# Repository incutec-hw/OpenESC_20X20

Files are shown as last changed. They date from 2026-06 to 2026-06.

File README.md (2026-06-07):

# OpenESC_20X20

<p>
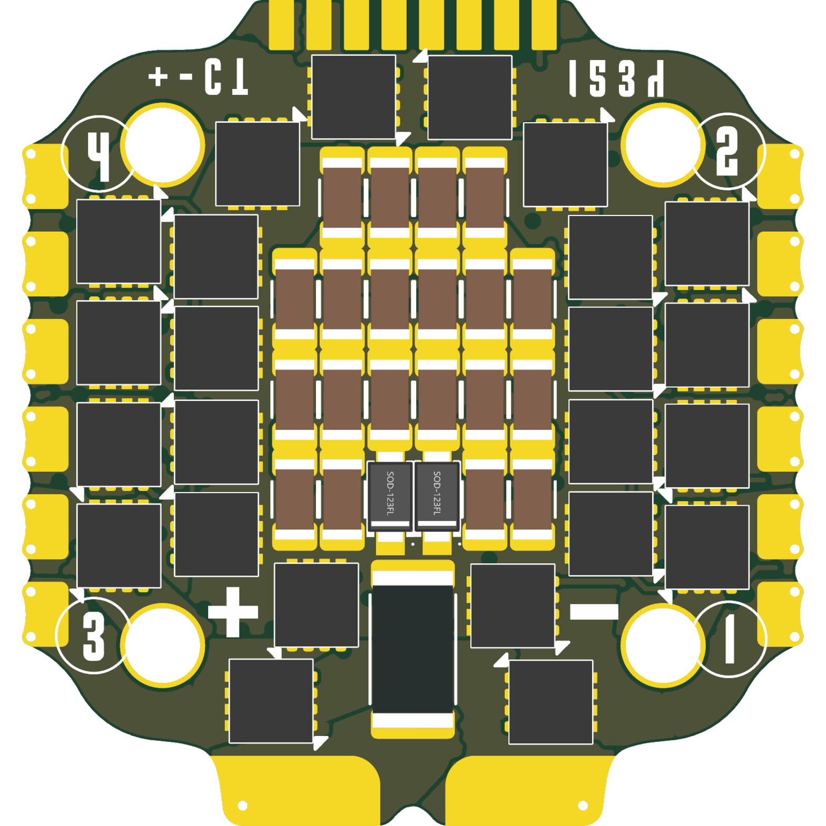
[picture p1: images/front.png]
OpenESC_20X20 top

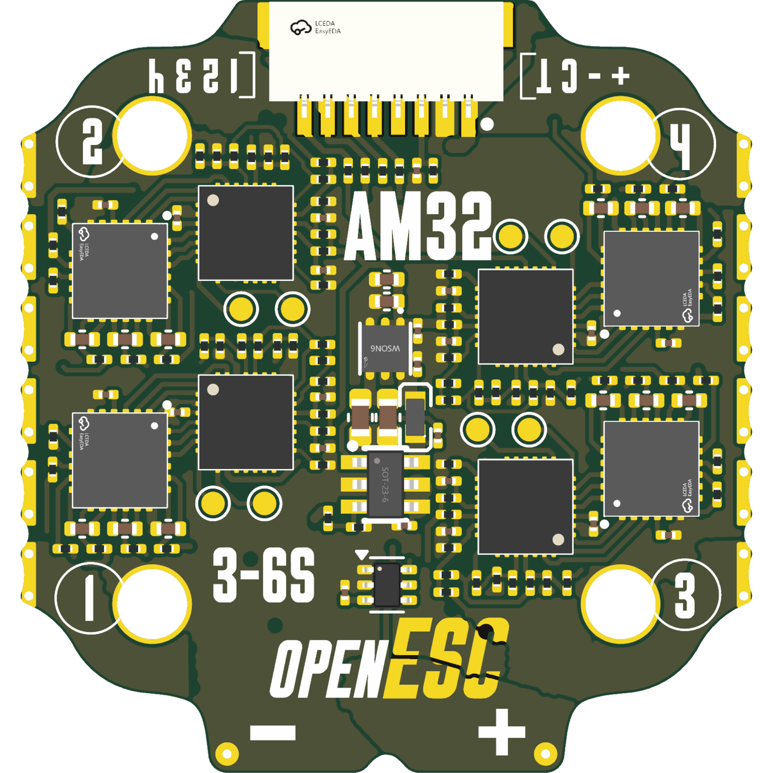
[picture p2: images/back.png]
OpenESC_20X20 bottom

</p>

Open-source 4-in-1 BLDC ESC with a 20 × 20 mm mounting pattern, built around four independent AT32F421 motor controllers running AM32. Six-layer, DShot over the standard 8-pin connector. Designed in KiCad for JLCPCB assembly.

Part of the incutec OpenDrone line (`incutec-hw/OpenESC_20X20`).

> A larger **[OpenESC-30x30](https://github.com/incutec-hw/OpenESC-30x30)** (30.5×30.5 mm) shares this design and mirrors this repo. The two differ only in board/mounting size and a few power-stage parts.

## Architecture

Four fully independent ESC channels share a common power input and telemetry connector. Each channel has its own MCU and gate driver; the high-current stage is six MOSFETs per channel (three half-bridges). This is the distributed-MCU AM32 4-in-1 topology rather than a single-MCU design. Values below are extracted from the KiCad design files (`hardware/4in1-mini.kicad_sch`, `hardware/ESC.kicad_sch`, `hardware/4in1-mini.kicad_pcb`) and the production BOM (`hardware/production/Rev2-20x20_bom.csv`).

| Block | Part | LCSC | Per board |
|---|---|---|---|
| Motor MCU | AT32F421G8U7 (QFN-28) | C2765098 | 4 |
| Gate driver | NSG2065Q (QFN-24) | C41414478 | 4 |
| Power MOSFETs | DOY180N03T PowerDI3333-8 | C49441966 | 24 (6 per channel) |

## Specifications

| Parameter | Value |
|---|---|
| Channels | 4 independent BLDC channels |
| MCU | AT32F421G8U7 (ARM Cortex-M4, QFN-28), one per channel |
| Gate driver | NSG2065Q (QFN-24, FD6288Q-compatible), one per channel |
| Power MOSFETs | DOY180N03T, 30 V, PowerDI3333-8, 24 total |
| Current sense | Board-level high-side: INA186A3IDCKR (100 V/V, SC-70-6) + 1× 0.2 mΩ 2512 shunt (Rsense1) in the +BATT feed → 20 mV/A → 165 A full-scale at 3.3 V ADC |
| Input | +BATT direct from connector/pads, 6S target |
| Input protection | 2× SMF24A-T13 TVS (24 V standoff) |
| Buck regulator | LMR54406DBVR (SOT-23-6) + FTC160808S4R7MBCA 4.7 µH inductor → +10 V gate-drive rail (FB 115k/10k, Vref 0.8 V → 10.0 V) |
| LDO | TLV76733DRVR (WSON-6) → +3V3 (MCUs, sensing), from +10 V |
| Signal protocol | DShot (4 independent signal lines, one per channel) |
| Firmware | AM32 (per-channel AT32F421 target, flashed individually) |
| PCB | 6-layer; outline ≈ 31.3 × 33.1 mm |
| Mounting pattern | 20 × 20 mm, 4× holes (M2) |

Current/voltage ratings are not printed on the design files. The input clamp is set by the SMF24A-T13 TVS (24 V standoff → 6S); the MOSFET (DOY180N03T) and current-sense full-scale (165 A) set the practical envelope. Characterize before quoting a hard rating.

## Connector

8-pin JST **SM08B-SRSS-TB** (J1). Pin-to-net mapping extracted from the schematic (net labels at the connector pins):

| Pin | Net | Function |
|---|---|---|
| 1 | +BATT | Battery positive |
| 2 | GND | Ground |
| 3 | /CURR | Current-sense telemetry (INA186 output) |
| 4 | *(unconnected)* | No dedicated telemetry pin — telemetry handled by extended DShot |
| 5 | /M1 | DShot signal, channel 1 |
| 6 | /M2 | DShot signal, channel 2 |
| 7 | /M3 | DShot signal, channel 3 |
| 8 | /M4 | DShot signal, channel 4 |

Connector ground returns on the shield/mounting pads P1/P2 (both GND). Pin 4 — the dedicated telemetry pin on the Betaflight 8-pin standard — is intentionally unconnected: ESC→FC telemetry is carried over the motor signal lines via the bidirectional **extended DShot** protocol.

## Variants and revisions

This repo is the 20×20 (mini) member of the OpenESC family; the 30×30 sibling lives in [`OpenESC-30x30`](https://github.com/incutec-hw/OpenESC-30x30). Production exports in `hardware/production/` show successive board spins; the current target is **Rev2-20x20** (`hardware/fabrication-toolkit-options.json` archive name `Rev2-20x20`). Earlier exports (`V1`, `V2`, `v0.1`–`v0.3`) are retained for history. Per the beta spec (`V_BETA_CHANGELIST.md`), this board is **6S only** (TVS-clamped); an 8S board is tracked as a separate SKU.

## Firmware

[AM32](https://github.com/AlkaMotors/AM32-MultiRotor-ESC-firmware) — incutec's default ESC firmware. Boards ship with the AM32 bootloader pre-loaded; firmware is flashed and configured in-browser at [am32.ca](https://am32.ca). Each channel's AT32F421G8U7 is an independent AM32 target. The AT32F421 + NSG2065Q per-channel topology and the DShot signal nets are the standard AM32 4-in-1 hardware target. Works with Betaflight and other DShot-capable flight controllers.

## Repository structure

```
README.md  LICENSE  CLAUDE.md            Repo root: docs + license + agent instructions
images/                                  Board render images
licensing/                               Hardware license, third-party notices, trademark policy
hardware/                                KiCad 9 project (everything to build/fab the board)
├── 4in1-mini.kicad_sch                  Top schematic (power, current sense, connector)
├── ESC.kicad_sch                        Single ESC channel sheet (instantiated 4×)
├── 4in1-mini.kicad_pcb                  Main board layout (6-layer)
├── 4in1-mini.kicad_pro                  Main project
├── components.kicad_sym                 Project-local symbol library
├── 4in1ESC.pretty/                      Project-local footprints
├── 4in1ESC.3dshapes/                   3D models (STEP)
├── fp-lib-table / sym-lib-table         Project-local library tables (${KIPRJMOD})
├── 4in1-mini.step / .glb                Exported board 3D models
├── production/                          JLCPCB fabrication exports (gerbers, BOM, CPL) per revision
├── fabrication-toolkit-options.json     KiCad Fabrication Toolkit settings
├── flash_openesc20.sh                   Production flash script (AM32 bootloader via ST-LINK)
├── datasheets/                          Component datasheets + COMPONENT_REVIEW.md
├── tools/ , scripts/                    Analysis scripts
├── V_BETA_CHANGELIST.md                 Beta spec: stackup/copper-weight, 6S-only rationale (local)
└── docs/archive/                        Design notes, alternatives, sourcing, cost analysis (local)
```

## License

Hardware: [CERN-OHL-S-2.0](https://ohwr.org/cern_ohl_s_v2.txt). See [LICENSE](LICENSE) and [licensing/](licensing/) for branding and third-party notices.

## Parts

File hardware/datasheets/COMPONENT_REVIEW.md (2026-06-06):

# Component Review — Commercial Release Audit (v0.3)

Full design review of all ICs and key components for commercial readiness.
Conducted March 2026.

---

## Critical Issues (Must Fix for v0.4)

### 1. TPS746-3.3DRV: Input Voltage Exceeds Absolute Maximum

**Severity: CRITICAL**

The TPS746-3.3DRV LDO has a maximum input voltage of 6.0V (abs max 6.5V), but the upstream LMR51420 buck converter outputs **8.04V** (set by 124kΩ/10kΩ feedback divider). This is a hard specification violation.

**Why it works in testing:** The TPS746 may survive at 8V in benign conditions, but will fail under temperature extremes, production variance, or extended operation. Not acceptable for commercial release.

**Fix:** Drop-in replacement with **TLV76733DRVR** (LCSC C2848334):
- Same WSON-6 2x2mm footprint — zero PCB changes
- Input range: 2.5V to **16V** (8V input with 2x margin)
- Output: 3.3V fixed, **1A** (upgrade from 500mA)
- Price: $0.10 (comparable to TPS746)
- Stock: 8,240 units on LCSC

**BOM change:** Replace U26 TPS746-3.3DRV (C524780) → TLV76733DRVR (C2848334)

---

### 2. INA199A1DCKR: Common-Mode Voltage Marginal for 6S

**Severity: CRITICAL**

The INA199A1 has a maximum common-mode input of **26V**. A 6S LiPo at full charge is 25.2V — only 0.8V (3%) margin. Inductive switching spikes from MOSFET commutation can easily push the battery rail to 27-28V transiently, exceeding absolute max and risking permanent damage.

**Fix:** Replace INA199A1DCKR with **INA293A2IDBVR** (LCSC C1855797):
- Common-mode range: **-4V to 110V** (vs 26V — massive margin)
- Gain: 100V/V (vs 50V/V — better ADC utilization)
- Offset: ±25µV max (vs ±150µV — 6x improvement)
- Bandwidth: 1.3 MHz (vs 14 kHz — 93x improvement)
- Package: SOT-23-5 (slightly larger than SC-70-6, requires footprint change)

With 0.2mΩ shunt and 100V/V gain:
| Load | Shunt voltage | ADC output | % of 3.3V |
|---|---|---|---|
| 140A (4×35A) | 28mV | 2.80V | 85% |
| 35A (1 channel) | 7mV | 700mV | 21% |
| 10A (cruise) | 2mV | 200mV | 6% |

**BOM change:** Replace U1 INA199A1DCKR (C59135) → INA293A2IDBVR (C1855797). Footprint change from SC-70-6 to SOT-23-5 required.

---

---

## Low / Informational Issues

### 6. R18 Footprint Mismatch
R18 (10kΩ NRST pull-up) uses a capacitor footprint (`C_0201_0603Metric`) instead of resistor footprint. Cosmetic/DRC issue — physically works but should be corrected for production DRC cleanliness.

### 7. Ferrite Beads (FB1-FB4) Need Part Assignment
Currently generic "200mA" ferrite beads with no specific part number or impedance spec. For commercial release, assign a specific part (e.g., 120Ω @ 100MHz, ≥200mA rated). Must be available on LCSC/JLCPCB in 0201 package.

---

## Components Verified OK

### LMR51420YDDCR Buck Converter — PASS

The 0.47µH inductor (XRIM160808SR47MBCD) is 10x smaller than textbook recommendation (4.7µH), but this is a deliberate size optimization that works because:
- Actual load is only ~500mA (4× MCU + 4× gate driver + misc), well below the 1.4A IC rating
- Operates in deep DCM (discontinuous conduction mode) — load current (500mA) << ripple/2 (5.25A)
- Output ripple on 8V rail: ~0.52V peak-to-peak (6.5%) at 6S
- Gate drivers (NSG2065Q) tolerate this easily — VCC stays within 7.48-8.56V, well inside 7-13.5V operating range
- LDO PSRR (65dB @ 1MHz) filters 8V ripple to **0.93mV** on the 3.3V MCU rail
- The 1.6×0.8mm inductor is critical for the compact 20×20mm board layout
- LMR51420 has cycle-by-cycle current limiting for inductor saturation protection

### NSG2065Q Gate Driver — PASS

- VCC at 8V is at recommended minimum, UVLO at 4.5V provides margin
- 1.2A source / 1.5A sink drive current — adequate for SP40N03GNJ gate charge
- 100nF bootstrap caps provide 8.5x margin over required gate charge
- 15Ω gate resistors are appropriate for controlled switching
- 200ns internal dead time prevents shoot-through

### SP40N03GNJ MOSFETs — PASS (with note)

- 40V VDS, 75A ID, 2.9mΩ RDS(on) @ 10V VGS
- Conduction loss per MOSFET at 17.5A RMS: ~0.89W — manageable
- Gate charge 26nC — well within NSG2065Q driver capability
- 3×3mm PDFN-8L package fits the 20×20mm board
- Proven thermally in hard flight testing
- Good price and LCSC/JLCPCB availability (C22466709)

**VDS margin note:** At 6S (25.2V), switching transients with ~20nH stray inductance and 35A/50ns di/dt can produce ~14V spikes, pushing VDS to ~39V on a 40V-rated part. This is tight but workable with good PCB layout (short power loops, cap placement close to MOSFETs). The board has been tested extensively at 6S without issues, confirming the layout handles this well. For the 30×30mm variant, consider 60V parts for additional margin.

### 0805 10µF 50V Bulk Capacitors (C440198) — PASS (Keep Current)

- GRM21BR61H106KE43L (Murata, X5R, 50V) retains ~60-70% capacitance at 25V DC bias → ~6-7µF effective per cap
- 33 caps × ~6.5µF = ~215µF effective total — adequate, proven in hard flight testing
- Alternative GCM31CD71H106KE36L (1206 X7T) is NOT available on LCSC/JLCPCB
- Switching to 1206 would only gain 15-20% more capacitance but requires PCB redesign and 85% more board area per cap
- X7T vs X5R DC bias performance is nearly identical; package size is the dominant factor
- Current design validated in field: no bulk electrolytic needed

### HC-1.0-8PWT Connector — NOTED
User handling connector standard migration separately (Betaflight 8-pin JST-SH standard).

---

## DOY170N04T MOSFET Evaluation (User Inquiry)

The DOINGTER DOY170N04T (LCSC C50386319) was evaluated as a potential MOSFET upgrade:
- 40V, 170A, 1.7mΩ RDS(on) @ 10V — significantly lower resistance than SP40N03GNJ (2.9mΩ)
- Package: TDFN3333-8PL (3.3×3.3mm) — slightly larger than current 3×3mm PDFN-8L
- Would reduce conduction losses by ~40%

**Assessment:** Not recommended for v0.4:
- DOINGTER is an unestablished brand with limited track record
- 3.3×3.3mm package is slightly larger — may not fit current 3×3mm footprint without layout changes
- Lower RDS(on) means higher gate charge (Qg) — need to verify NSG2065Q can drive 6 of these per channel
- SP40N03GNJ is proven, cheaper, and thermally adequate in testing

---

## SP40N01GHNK — Candidate for 30×30mm Variant

**Siliup SP40N01GHNK** (LCSC C22385416) — same manufacturer as the SP40N03GNJ, in 5×6mm PDFN-8L.

| Parameter | SP40N03GNJ (20×20) | SP40N01GHNK (30×30 candidate) |
|---|---|---|
| VDS | 40V | 40V |
| ID (package) | 75A | 120A |
| ID (silicon) | — | 230A |
| RDS(on) @ 10V | 2.9mΩ | **1.2mΩ typ / 1.5mΩ max** |
| RDS(on) @ 4.5V | — | ~1.6mΩ (from RDS vs ID curve) |
| Qg | 26nC | **126nC** |
| Qgd | — | 15.5nC |
| Ciss | — | 5750pF |
| Rise / Fall | — | 5ns / 9.5ns |
| RθJC | ~2°C/W (est.) | **0.96°C/W** |
| PD | 55W | **130W** |
| EAS | not published | **1089mJ** (published!) |
| Package | PDFN-8L 3×3mm | PDFN5X6-8L **5×6mm** |
| Price | ~$0.15-0.20 | **$0.21** |
| LCSC stock | In stock | 4,535 units |

**Assessment: Strong candidate for 30×30mm variant.**

Pros:
- Same manufacturer family — proven silicon quality, consistent supply chain
- 58% lower RDS(on) (1.2mΩ vs 2.9mΩ) → ~58% lower conduction losses
- Published EAS (1089mJ) — avalanche-rated, unlike the SP40N03GNJ
- 0.96°C/W RθJC vs ~2°C/W — much better thermal performance
- Comparable price

Cons:
- Qg is 4.8× higher (126nC vs 26nC) — impacts gate driver loading
- JLCPCB assembly availability needs verification

**Gate driver compatibility check:** With 126nC Qg per MOSFET, the NSG2065Q bootstrap cap (100nF) needs to supply enough charge for the high-side MOSFET each PWM cycle. Per high-side MOSFET: 126nC required. Bootstrap cap at 8V: 100nF × 8V = 800nC available. With one high-side MOSFET switching per phase: 800/126 = 6.3× margin. **Still adequate**, though tighter than the SP40N03GNJ (800/26 = 30× margin). Consider increasing bootstrap cap to 220nF for extra margin on the 30×30 variant.

Gate switching with 15Ω gate resistor: peak gate current ≈ (8V - 3V) / 15Ω ≈ 333mA, switching time ≈ 126nC / 333mA ≈ 378ns. This is slower than the SP40N03GNJ (~78ns). For 24kHz PWM (41.7µs period), 378ns is still <1% of the cycle — acceptable. Consider reducing gate resistance to 10Ω on the 30×30 variant if faster switching is desired.

---

## Summary of Required BOM Changes for v0.4

| Ref | Current Part | LCSC | New Part | LCSC | Change Type |
|-----|---|---|---|---|---|
| U26 | TPS746-3.3DRV | C524780 | TLV76733DRVR | C2848334 | Drop-in (same WSON-6 footprint) |
| U1 | INA199A1DCKR | C59135 | INA293A2IDBVR | C1855797 | Footprint change (SC-70-6 → SOT-23-5) |

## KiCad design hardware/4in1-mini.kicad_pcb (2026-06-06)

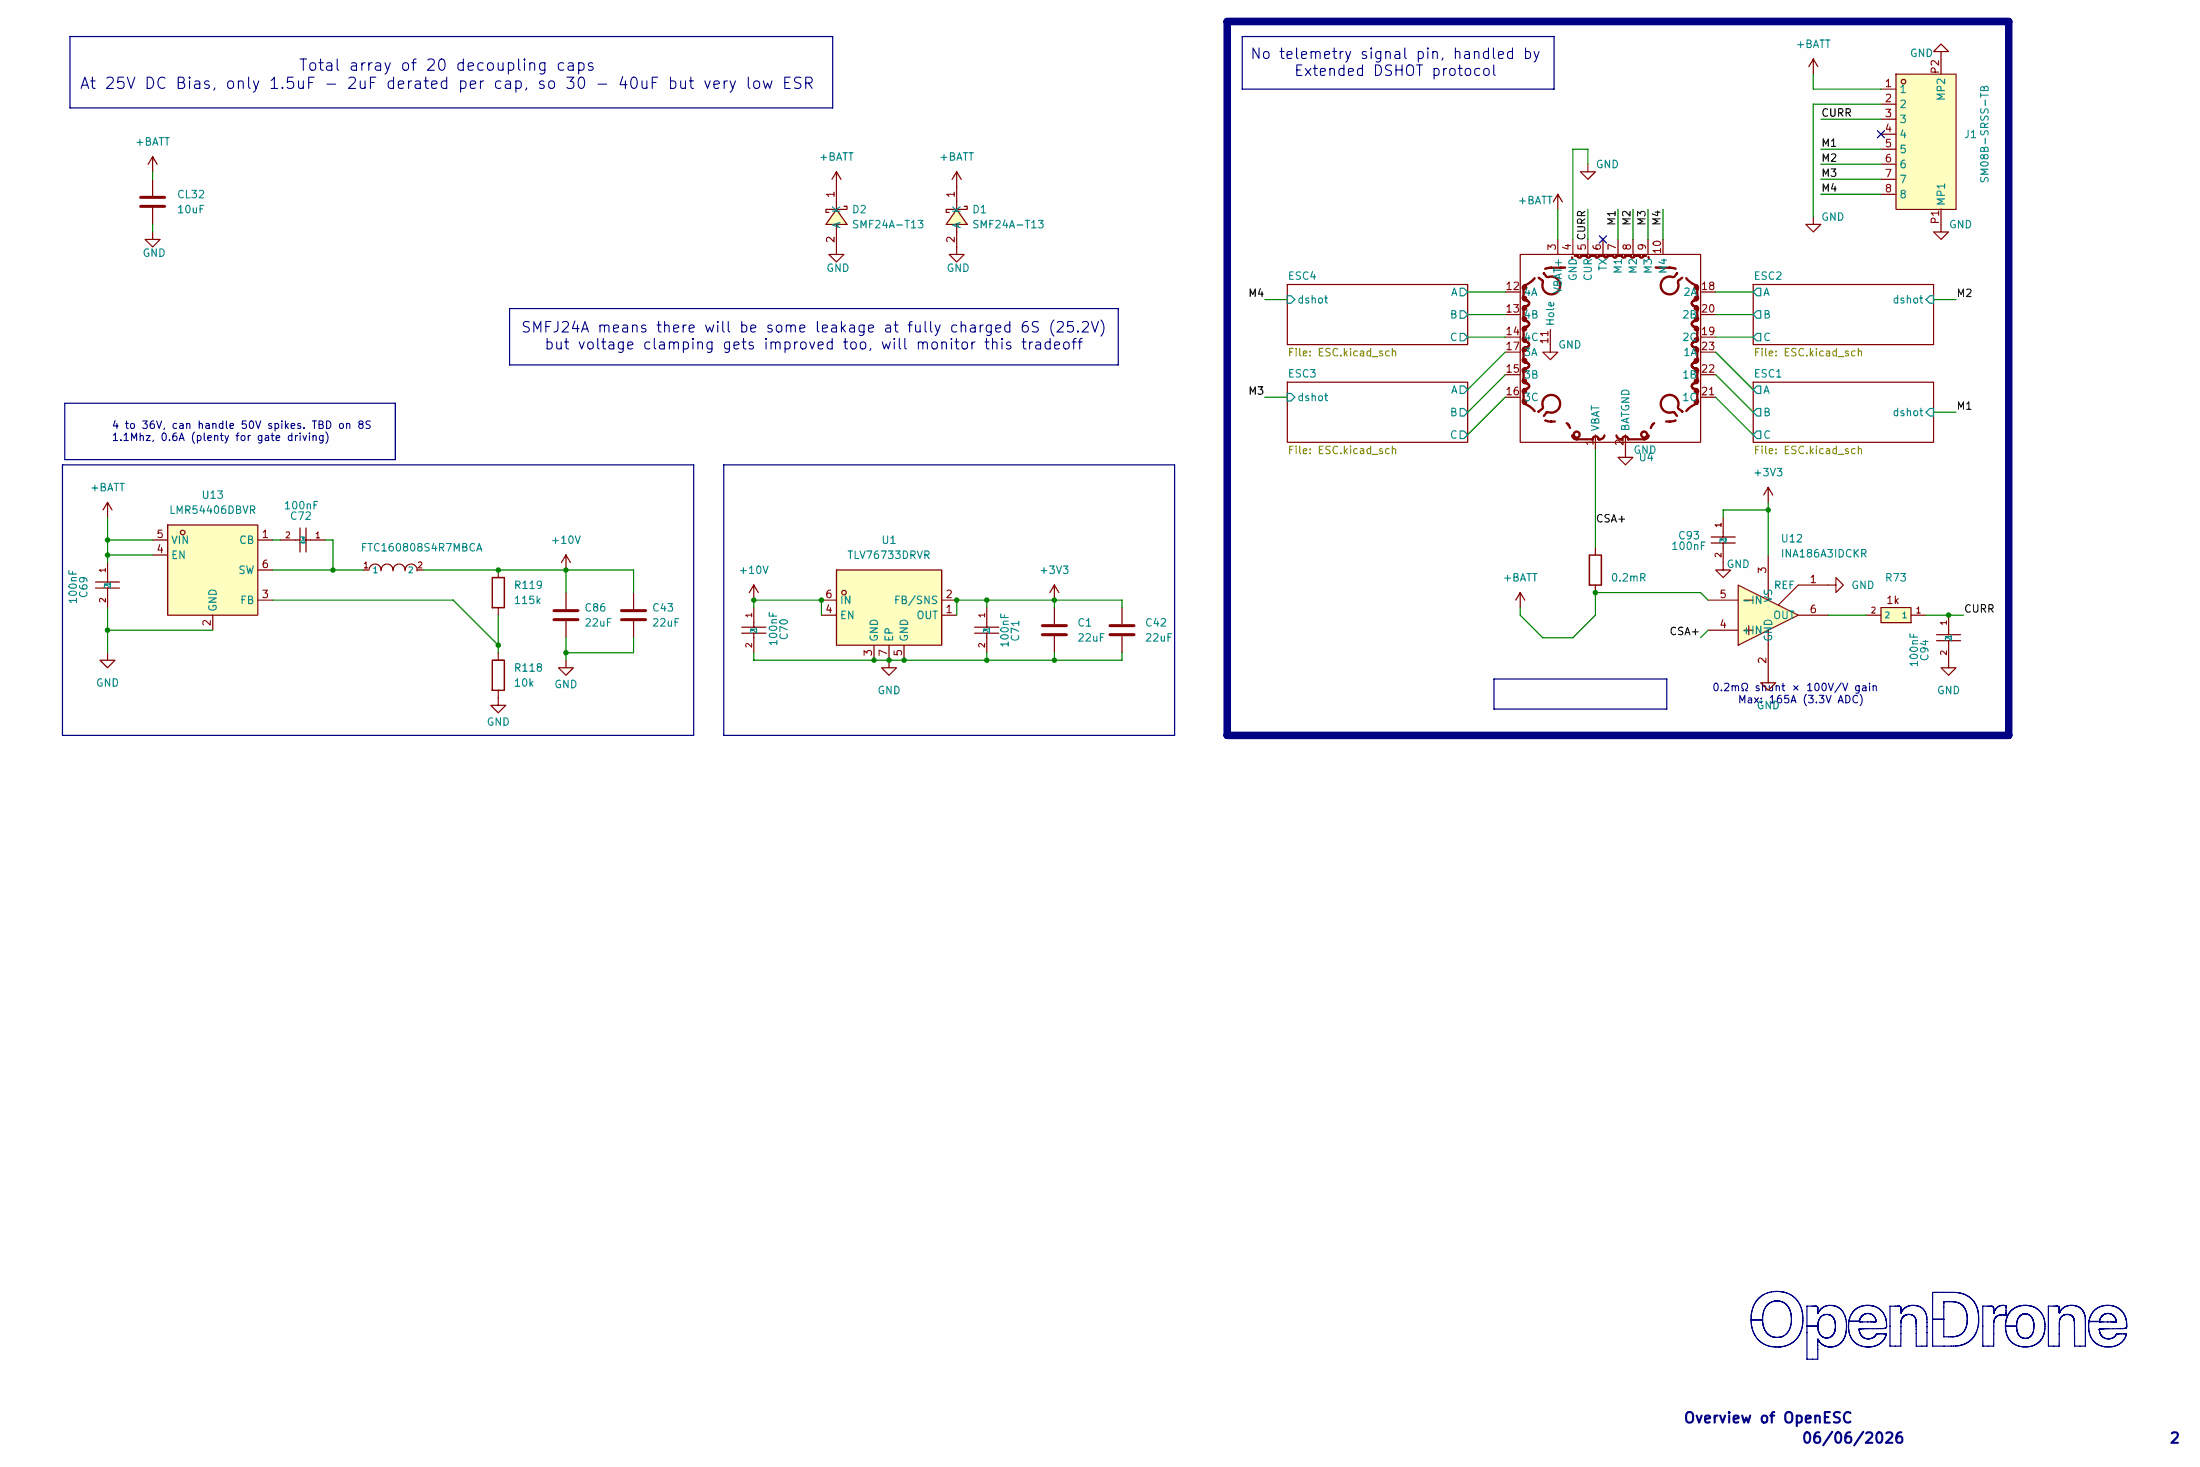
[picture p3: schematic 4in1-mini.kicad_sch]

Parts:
C1, C42: 22uF; C_0402_1005Metric; MPN CL05A226MQ5QUNC; LCSC C105226
C43, C86: 22uF; C_0603_1608Metric; MPN CL10A226MO7JZNC; LCSC C2762594
C69, C70, C71, C72, C93, C94: 100nF; C_0201_0603Metric; MPN GRM033R6YA104KE14D; LCSC C181043
CL32: 10uF; C_1206_3216Metric; MPN CL31B106KBHNNNE; LCSC C89632
D1, D2: SMF24A-T13; SOD-123FL_L2.7-W1.8-LS3.7-RD; MPN SMF24A-T13; LCSC Part C1977154
J1: SM08B-SRSS-TB; JST_SM08B-SRSS-TB; MPN SM08B-SRSS-TB(LF)(SN); LCSC C160407
R73: 1k; R_0201_0603Metric; MPN 0201WMF1001TEE; LCSC C270365
R118: 10k; R_0201_0603Metric; MPN RC0201FR-0710KL; LCSC C106225
R119: 115k; R_0201_0603Metric; MPN RTT011153FTH; LCSC C166378
Rsense1: 0.2mR; R_2512_6332Metric; MPN ASR-S-3-0.2F; LCSC C695806
U1: TLV76733DRVR; WSON-6_L2.0-W2.0-P0.65-TL-EP; MPN TLV76733DRVR; LCSC C2848334
U4: 4in1ESC
U5: FTC160808S4R7MBCA; IND-SMD_L1.6-W0.8_FTC160865SR47MBCA; MPN FTC160808S4R7MBCA; LCSC C46594347
U12: INA186A3IDCKR; SOT-363_SC-70-6; MPN INA186A3IDCKR; LCSC C2058245
U13: LMR54406DBVR; SOT-23-6_L2.9-W1.6-P0.95-LS2.8-BR; MPN LMR54406DBVR; LCSC Part C5219316

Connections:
+3V3: C1.2, C42.2, C71.1, C93.1, U1.1 (OUT), U1.2 (FB/SNS), U12.3 (VS); also elsewhere on the board
+10V: C43.1, C70.1, C86.1, R119.1, U1.4 (EN), U1.6 (IN), U5.2; also elsewhere on the board
+BATT: C69.1, CL32.1, D1.1 (K), D2.1 (K), J1.1, Rsense1.2, U4.3 (VBAT+), U12.5 (-IN), U13.4 (EN), U13.5 (VIN); also elsewhere on the board
/CSA+: Rsense1.1, U4.1 (VBAT), U12.4 (+IN)
/CURR: C94.1, J1.3, R73.1, U4.5 (CUR)
/ESC1/MotorA: U4.23 (1A); also elsewhere on the board
/ESC1/MotorB: U4.22 (1B); also elsewhere on the board
/ESC1/MotorC: U4.21 (1C); also elsewhere on the board
/ESC2/MotorA: U4.18 (2A); also elsewhere on the board
/ESC2/MotorB: U4.20 (2B); also elsewhere on the board
/ESC2/MotorC: U4.19 (2C); also elsewhere on the board
/ESC3/MotorA: U4.17 (3A); also elsewhere on the board
/ESC3/MotorB: U4.15 (3B); also elsewhere on the board
/ESC3/MotorC: U4.16 (3C); also elsewhere on the board
/ESC4/MotorA: U4.12 (4A); also elsewhere on the board
/ESC4/MotorB: U4.13 (4B); also elsewhere on the board
/ESC4/MotorC: U4.14 (4C); also elsewhere on the board
/M1: J1.5, U4.7 (M1); also elsewhere on the board
/M2: J1.6, U4.8 (M2); also elsewhere on the board
/M3: J1.7, U4.9 (M3); also elsewhere on the board
/M4: J1.8, U4.10 (M4); also elsewhere on the board
GND: C1.1, C42.1, C43.2, C69.2, C70.2, C71.2, C86.2, C93.2, C94.2, CL32.2, D1.2 (A), D2.2 (A), J1.2, J1.P1 (MP1), J1.P2 (MP2), R118.2, U1.3 (GND), U1.5 (GND), U1.7 (EP), U4.2 (BATGND), U4.4 (GND), U4.11 (Hole), U12.1 (REF), U12.2 (GND), U13.2 (GND); also elsewhere on the board
unnamed: R73.2, U12.6 (OUT)
unnamed: C72.2, U13.1 (CB)
unnamed: R118.1, R119.2, U13.3 (FB)
unnamed: C72.1, U5.1, U13.6 (SW)

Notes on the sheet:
06/06/2026
No telemetry signal pin, handled by Extended DSHOT protocol
4 to 36V, can handle 50V spikes. TBD on 8S 1.1Mhz, 0.6A (plenty for gate driving)
SMFJ24A means there will be some leakage at fully charged 6S (25.2V) but voltage clamping gets improved too, will monitor this tradeoff
Overview of OpenESC
Total array of 20 decoupling caps At 25V DC Bias, only 1.5uF - 2uF derated per cap, so 30 - 40uF but very low ESR
0.2mΩ shunt × 100V/V gain Max: 165A (3.3V ADC)

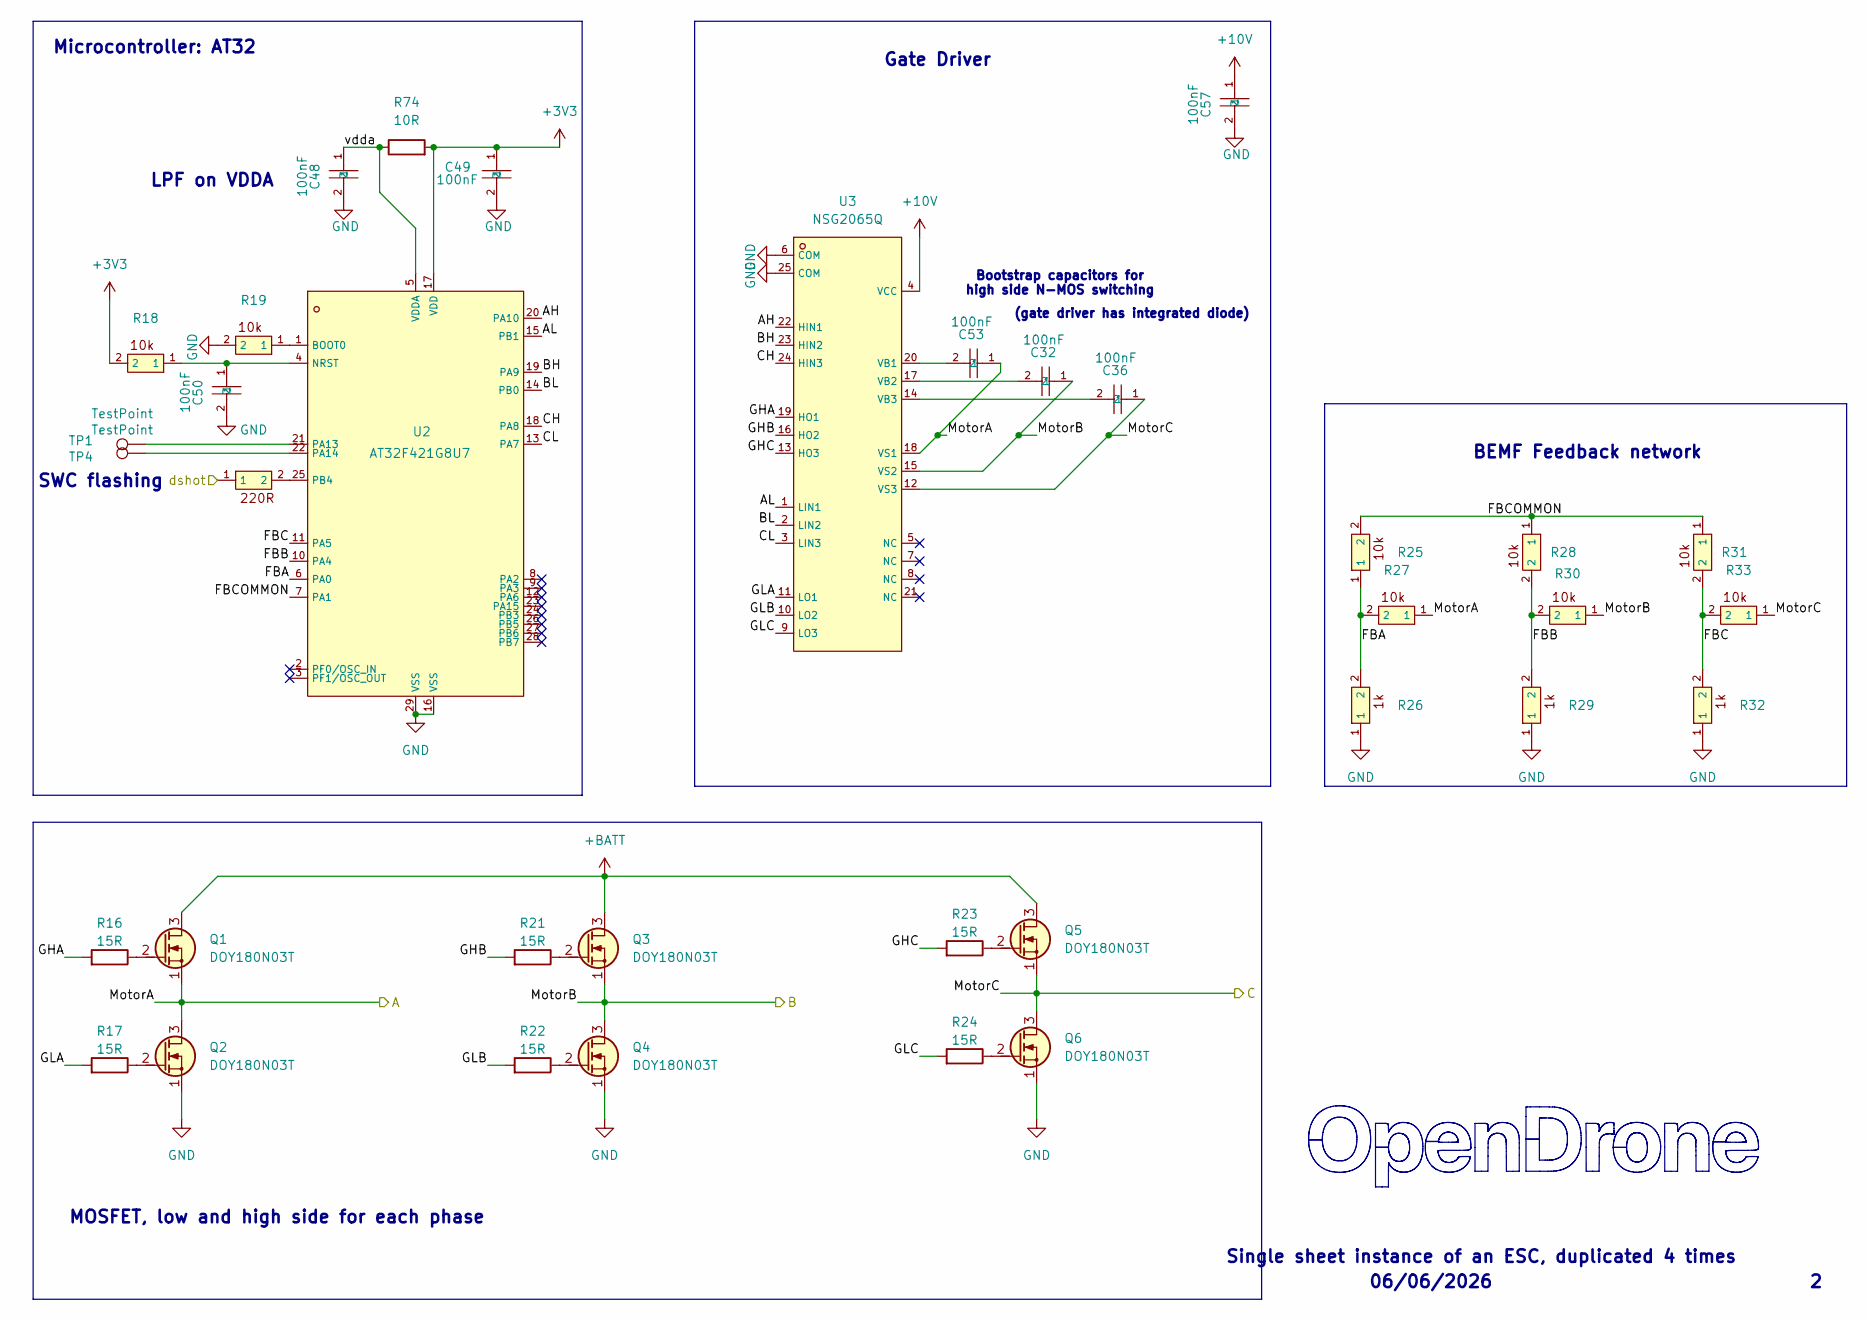
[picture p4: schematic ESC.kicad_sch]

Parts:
C32, C36, C53: 100nF; C_0402_WIDE; MPN CL05B104KB54PNC; LCSC C307331
C48, C49, C50, C57: 100nF; C_0201_0603Metric; MPN GRM033R6YA104KE14D; LCSC C181043
Q1, Q2, Q3, Q4, Q5, Q6: DOY180N03T; Diodes_PowerDI3333-8; MPN DOY180N03T; LCSC C49441966
R16, R17, R21, R22, R23, R24: 15R; R_0201_0603Metric; MPN 0201WMF150JTEE; LCSC C473542
R18, R19, R25, R27, R28, R30, R31, R33: 10k; R_0201_0603Metric; MPN RC0201FR-0710KL; LCSC C106225
R20: 220R; R_0201_0603Metric; MPN AC0201FR-07220RL; LCSC C226468
R26, R29, R32: 1k; R_0201_0603Metric; MPN 0201WMF1001TEE; LCSC C270365
R74: 10R; R_0201_0603Metric; MPN RC0201FR-0710RL; LCSC C106226
TP1, TP4: TestPoint; TestPoint_Pad_D1.0mm
U2: AT32F421G8U7; QFN-28_L4.0-W4.0-P0.40-TL-EP2.4; MPN AT32F421G8U7; LCSC C2765098
U3: NSG2065Q; QFN-24_L4.0-W4.0-P0.50-TL-EP2.8; MPN NSG2065Q; LCSC C41414478

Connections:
+3V3: C49.1, R18.2, R74.2, U2.17 (VDD); also elsewhere on the board
+10V: C57.1, U3.4 (VCC); also elsewhere on the board
+BATT: Q1.3 (D), Q3.3 (D), Q5.3 (D); also elsewhere on the board
/ESC1/AH: U2.20 (PA10), U3.22 (HIN1)
/ESC1/AL: U2.15 (PB1), U3.1 (LIN1)
/ESC1/BH: U2.19 (PA9), U3.23 (HIN2)
/ESC1/BL: U2.14 (PB0), U3.2 (LIN2)
/ESC1/CH: U2.18 (PA8), U3.24 (HIN3)
/ESC1/CL: U2.13 (PA7), U3.3 (LIN3)
/ESC1/FBA: R25.1, R26.2, R27.2, U2.6 (PA0)
/ESC1/FBB: R28.2, R29.2, R30.2, U2.10 (PA4)
/ESC1/FBC: R31.2, R32.2, R33.2, U2.11 (PA5)
/ESC1/FBCOMMON: R25.2, R28.1, R31.1, U2.7 (PA1)
/ESC1/GHA: R16.1, U3.19 (HO1)
/ESC1/GHB: R21.1, U3.16 (HO2)
/ESC1/GHC: R23.1, U3.13 (HO3)
/ESC1/GLA: R17.1, U3.11 (LO1)
/ESC1/GLB: R22.1, U3.10 (LO2)
/ESC1/GLC: R24.1, U3.9 (LO3)
/ESC1/MotorA: C53.1, Q1.1 (S), Q2.3 (D), R27.1, U3.18 (VS1); also elsewhere on the board
/ESC1/MotorB: C32.1, Q3.1 (S), Q4.3 (D), R30.1, U3.15 (VS2); also elsewhere on the board
/ESC1/MotorC: C36.1, Q5.1 (S), Q6.3 (D), R33.1, U3.12 (VS3); also elsewhere on the board
/ESC1/vdda: C48.1, R74.1, U2.5 (VDDA)
/M1: R20.1; also elsewhere on the board
GND: C48.2, C49.2, C50.2, C57.2, Q2.1 (S), Q4.1 (S), Q6.1 (S), R19.2, R26.1, R29.1, R32.1, U2.16 (VSS), U2.29 (VSS), U3.6 (COM), U3.25 (COM); also elsewhere on the board
unnamed: Q1.2 (G), R16.2
unnamed: Q2.2 (G), R17.2
unnamed: Q3.2 (G), R21.2
unnamed: Q4.2 (G), R22.2
unnamed: Q5.2 (G), R23.2
unnamed: Q6.2 (G), R24.2
unnamed: R19.1, U2.1 (BOOT0)
unnamed: C50.1, R18.1, U2.4 (NRST)
unnamed: TP1.1 (1_1), U2.21 (PA13)
unnamed: TP4.1 (1_1), U2.22 (PA14)
unnamed: R20.2, U2.25 (PB4)
unnamed: C53.2, U3.20 (VB1)
unnamed: C32.2, U3.17 (VB2)
unnamed: C36.2, U3.14 (VB3)

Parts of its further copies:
C33, C34, C35, C37, C38, C39, C59, C73, C83: 100nF; C_0402_WIDE; MPN CL05B104KB54PNC; LCSC C307331
C44, C45, C46, C63, C64, C65, C66, C77, C78, C79, C80, C88: 100nF; C_0201_0603Metric; MPN GRM033R6YA104KE14D; LCSC C181043
Q7, Q8, Q9, Q10, Q11, Q12, Q13, Q14, Q15, Q16, Q17, Q18, Q19, Q20, Q21, Q22, Q23, Q24: DOY180N03T; Diodes_PowerDI3333-8; MPN DOY180N03T; LCSC C49441966
R1, R2, R6, R7, R8, R9, R37, R38, R42, R43, R44, R45, R55, R56, R60, R61, R62, R63: 15R; R_0201_0603Metric; MPN 0201WMF150JTEE; LCSC C473542
R3, R4, R10, R12, R13, R15, R34, R36, R39, R40, R46, R48, R49, R51, R52, R54, R57, R58, R64, R66, R67, R69, R70, R72: 10k; R_0201_0603Metric; MPN RC0201FR-0710KL; LCSC C106225
R5, R41, R59: 220R; R_0201_0603Metric; MPN AC0201FR-07220RL; LCSC C226468
R11, R14, R35, R47, R50, R53, R65, R68, R71: 1k; R_0201_0603Metric; MPN 0201WMF1001TEE; LCSC C270365
R75, R76, R77: 10R; R_0201_0603Metric; MPN RC0201FR-0710RL; LCSC C106226
TP2, TP3, TP5, TP6, TP7, TP8: TestPoint; TestPoint_Pad_D1.0mm
U6, U8, U10: AT32F421G8U7; QFN-28_L4.0-W4.0-P0.40-TL-EP2.4; MPN AT32F421G8U7; LCSC C2765098
U7, U9, U11: NSG2065Q; QFN-24_L4.0-W4.0-P0.50-TL-EP2.8; MPN NSG2065Q; LCSC C41414478

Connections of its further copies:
+3V3: C45.1, C65.1, C79.1, R3.2, R39.2, R57.2, R75.2, R76.2, R77.2, U6.17 (VDD), U8.17 (VDD), U10.17 (VDD); also elsewhere on the board
+10V: C63.1, C77.1, C88.1, U7.4 (VCC), U9.4 (VCC), U11.4 (VCC); also elsewhere on the board
+BATT: Q7.3 (D), Q9.3 (D), Q11.3 (D), Q13.3 (D), Q15.3 (D), Q17.3 (D), Q19.3 (D), Q21.3 (D), Q23.3 (D); also elsewhere on the board
/ESC2/AH: U6.20 (PA10), U7.22 (HIN1)
/ESC2/AL: U6.15 (PB1), U7.1 (LIN1)
/ESC2/BH: U6.19 (PA9), U7.23 (HIN2)
/ESC2/BL: U6.14 (PB0), U7.2 (LIN2)
/ESC2/CH: U6.18 (PA8), U7.24 (HIN3)
/ESC2/CL: U6.13 (PA7), U7.3 (LIN3)
/ESC2/FBA: R10.1, R11.2, R12.2, U6.6 (PA0)
/ESC2/FBB: R13.2, R14.2, R15.2, U6.10 (PA4)
/ESC2/FBC: R34.2, R35.2, R36.2, U6.11 (PA5)
/ESC2/FBCOMMON: R10.2, R13.1, R34.1, U6.7 (PA1)
/ESC2/GHA: R1.1, U7.19 (HO1)
/ESC2/GHB: R6.1, U7.16 (HO2)
/ESC2/GHC: R8.1, U7.13 (HO3)
/ESC2/GLA: R2.1, U7.11 (LO1)
/ESC2/GLB: R7.1, U7.10 (LO2)
/ESC2/GLC: R9.1, U7.9 (LO3)
/ESC2/MotorA: C59.1, Q7.1 (S), Q8.3 (D), R12.1, U7.18 (VS1); also elsewhere on the board
/ESC2/MotorB: C33.1, Q9.1 (S), Q10.3 (D), R15.1, U7.15 (VS2); also elsewhere on the board
/ESC2/MotorC: C37.1, Q11.1 (S), Q12.3 (D), R36.1, U7.12 (VS3); also elsewhere on the board
/ESC2/vdda: C44.1, R75.1, U6.5 (VDDA)
/ESC3/AH: U8.20 (PA10), U9.22 (HIN1)
/ESC3/AL: U8.15 (PB1), U9.1 (LIN1)
/ESC3/BH: U8.19 (PA9), U9.23 (HIN2)
/ESC3/BL: U8.14 (PB0), U9.2 (LIN2)
/ESC3/CH: U8.18 (PA8), U9.24 (HIN3)
/ESC3/CL: U8.13 (PA7), U9.3 (LIN3)
/ESC3/FBA: R46.1, R47.2, R48.2, U8.6 (PA0)
/ESC3/FBB: R49.2, R50.2, R51.2, U8.10 (PA4)
/ESC3/FBC: R52.2, R53.2, R54.2, U8.11 (PA5)
/ESC3/FBCOMMON: R46.2, R49.1, R52.1, U8.7 (PA1)
/ESC3/GHA: R37.1, U9.19 (HO1)
/ESC3/GHB: R42.1, U9.16 (HO2)
/ESC3/GHC: R44.1, U9.13 (HO3)
/ESC3/GLA: R38.1, U9.11 (LO1)
/ESC3/GLB: R43.1, U9.10 (LO2)
/ESC3/GLC: R45.1, U9.9 (LO3)
/ESC3/MotorA: C73.1, Q13.1 (S), Q14.3 (D), R48.1, U9.18 (VS1); also elsewhere on the board
/ESC3/MotorB: C34.1, Q15.1 (S), Q16.3 (D), R51.1, U9.15 (VS2); also elsewhere on the board
/ESC3/MotorC: C38.1, Q17.1 (S), Q18.3 (D), R54.1, U9.12 (VS3); also elsewhere on the board
/ESC3/vdda: C64.1, R76.1, U8.5 (VDDA)
/ESC4/AH: U10.20 (PA10), U11.22 (HIN1)
/ESC4/AL: U10.15 (PB1), U11.1 (LIN1)
/ESC4/BH: U10.19 (PA9), U11.23 (HIN2)
/ESC4/BL: U10.14 (PB0), U11.2 (LIN2)
/ESC4/CH: U10.18 (PA8), U11.24 (HIN3)
/ESC4/CL: U10.13 (PA7), U11.3 (LIN3)
/ESC4/FBA: R64.1, R65.2, R66.2, U10.6 (PA0)
/ESC4/FBB: R67.2, R68.2, R69.2, U10.10 (PA4)
/ESC4/FBC: R70.2, R71.2, R72.2, U10.11 (PA5)
/ESC4/FBCOMMON: R64.2, R67.1, R70.1, U10.7 (PA1)
/ESC4/GHA: R55.1, U11.19 (HO1)
/ESC4/GHB: R60.1, U11.16 (HO2)
/ESC4/GHC: R62.1, U11.13 (HO3)
/ESC4/GLA: R56.1, U11.11 (LO1)
/ESC4/GLB: R61.1, U11.10 (LO2)
/ESC4/GLC: R63.1, U11.9 (LO3)
/ESC4/MotorA: C83.1, Q19.1 (S), Q20.3 (D), R66.1, U11.18 (VS1); also elsewhere on the board
/ESC4/MotorB: C35.1, Q21.1 (S), Q22.3 (D), R69.1, U11.15 (VS2); also elsewhere on the board
/ESC4/MotorC: C39.1, Q23.1 (S), Q24.3 (D), R72.1, U11.12 (VS3); also elsewhere on the board
/ESC4/vdda: C78.1, R77.1, U10.5 (VDDA)
/M2: R5.1; also elsewhere on the board
/M3: R41.1; also elsewhere on the board
/M4: R59.1; also elsewhere on the board
GND: C44.2, C45.2, C46.2, C63.2, C64.2, C65.2, C66.2, C77.2, C78.2, C79.2, C80.2, C88.2, Q8.1 (S), Q10.1 (S), Q12.1 (S), Q14.1 (S), Q16.1 (S), Q18.1 (S), Q20.1 (S), Q22.1 (S), Q24.1 (S), R4.2, R11.1, R14.1, R35.1, R40.2, R47.1, R50.1, R53.1, R58.2, R65.1, R68.1, R71.1, U6.16 (VSS), U6.29 (VSS), U7.6 (COM), U7.25 (COM), U8.16 (VSS), U8.29 (VSS), U9.6 (COM), U9.25 (COM), U10.16 (VSS), U10.29 (VSS), U11.6 (COM), U11.25 (COM); also elsewhere on the board
unnamed: Q7.2 (G), R1.2
unnamed: Q8.2 (G), R2.2
unnamed: Q9.2 (G), R6.2
unnamed: Q10.2 (G), R7.2
unnamed: Q11.2 (G), R8.2
unnamed: Q12.2 (G), R9.2
unnamed: Q13.2 (G), R37.2
unnamed: Q14.2 (G), R38.2
unnamed: Q15.2 (G), R42.2
unnamed: Q16.2 (G), R43.2
unnamed: Q17.2 (G), R44.2
unnamed: Q18.2 (G), R45.2
unnamed: Q19.2 (G), R55.2
unnamed: Q20.2 (G), R56.2
unnamed: Q21.2 (G), R60.2
unnamed: Q22.2 (G), R61.2
unnamed: Q23.2 (G), R62.2
unnamed: Q24.2 (G), R63.2
unnamed: R4.1, U6.1 (BOOT0)
unnamed: C46.1, R3.1, U6.4 (NRST)
unnamed: TP2.1 (1_1), U6.21 (PA13)
unnamed: TP3.1 (1_1), U6.22 (PA14)
unnamed: R5.2, U6.25 (PB4)
unnamed: C59.2, U7.20 (VB1)
unnamed: C33.2, U7.17 (VB2)
unnamed: C37.2, U7.14 (VB3)
unnamed: R40.1, U8.1 (BOOT0)
unnamed: C66.1, R39.1, U8.4 (NRST)
unnamed: TP5.1 (1_1), U8.21 (PA13)
unnamed: TP6.1 (1_1), U8.22 (PA14)
unnamed: R41.2, U8.25 (PB4)
unnamed: C73.2, U9.20 (VB1)
unnamed: C34.2, U9.17 (VB2)
unnamed: C38.2, U9.14 (VB3)
unnamed: R58.1, U10.1 (BOOT0)
unnamed: C80.1, R57.1, U10.4 (NRST)
unnamed: TP7.1 (1_1), U10.21 (PA13)
unnamed: TP8.1 (1_1), U10.22 (PA14)
unnamed: R59.2, U10.25 (PB4)
unnamed: C83.2, U11.20 (VB1)
unnamed: C35.2, U11.17 (VB2)
unnamed: C39.2, U11.14 (VB3)

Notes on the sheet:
Bootstrap capacitors for high side N-MOS switching
Gate Driver
MOSFET, low and high side for each phase
Single sheet instance of an ESC, duplicated 4 times
Microcontroller: AT32
SWC flashing
(gate driver has integrated diode)
06/06/2026
BEMF Feedback network
LPF on VDDA

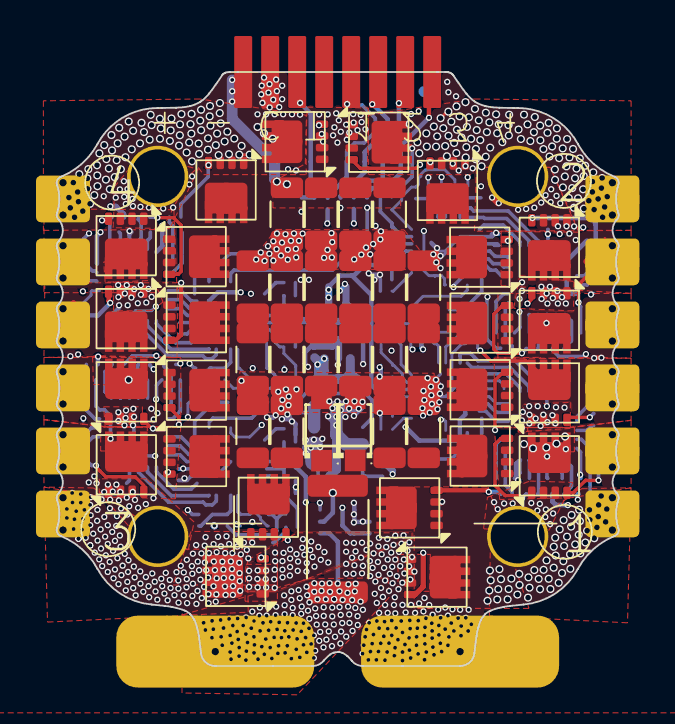
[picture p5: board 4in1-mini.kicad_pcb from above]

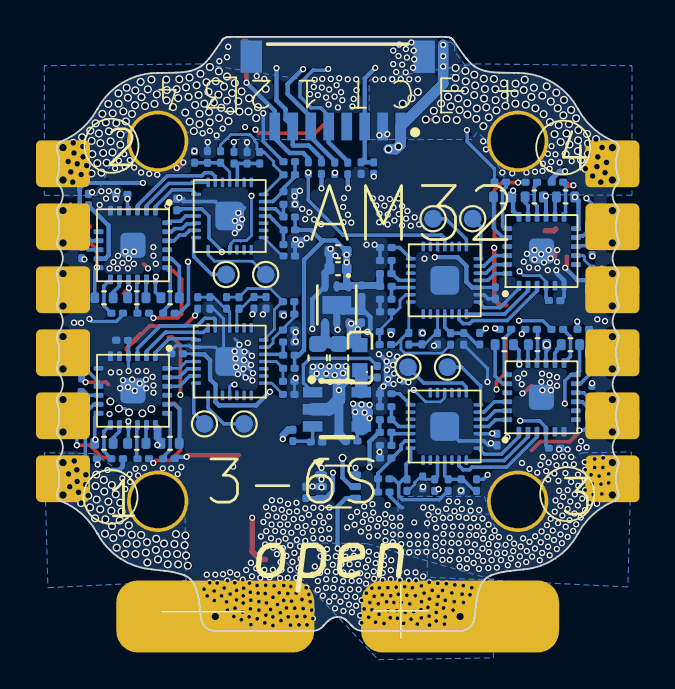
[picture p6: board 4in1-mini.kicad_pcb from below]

Board: 6 copper layers, 31.2 x 33.0 mm, 186 parts (138 on the bottom side), 150 nets.

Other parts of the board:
CL33, CL34, CL35, CL36, CL38, CL39, CL40, CL42, CL43, CL44, CL45, CL46, CL47, CL48, CL49, CL50, CL51, CL54, CL55: 10uF; C_1206_3216Metric

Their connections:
+BATT: CL33.1, CL34.1, CL35.1, CL36.1, CL38.1, CL39.1, CL40.1, CL42.1, CL43.1, CL44.1, CL45.1, CL46.1, CL47.1, CL48.1, CL49.1, CL50.1, CL51.1, CL54.1, CL55.1; also elsewhere on the board
GND: CL33.2, CL34.2, CL35.2, CL36.2, CL38.2, CL39.2, CL40.2, CL42.2, CL43.2, CL44.2, CL45.2, CL46.2, CL47.2, CL48.2, CL49.2, CL50.2, CL51.2, CL54.2, CL55.2; also elsewhere on the board

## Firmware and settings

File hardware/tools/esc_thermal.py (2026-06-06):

#!/usr/bin/env python3
"""
4in1 ESC Power Loss & Thermal Calculator

Models AM32 trapezoidal 6-step commutation with steady-state and transient thermal.
Supports both 20x20 and 30x30 ESC variants with datasheet-verified parameters.

Datasheets:
  20x20: SP40N03GNJ (Siliup Ver-1.2) + NSG2065Q (NSIC V1.0), Rg=15Ω
  30x30: SP40N01GHNK (Siliup Ver-1.1) + NSG2065Q (NSIC V1.0), Rg=8Ω
"""

import argparse
import math

# ═══════════════════════════════════════════════════════════════
#  MOSFET profiles — all values from datasheets
# ═══════════════════════════════════════════════════════════════

PROFILES = {
    "20x20": {
        "name":         "20×20  SP40N03GNJ (3×3mm)",
        # ── SP40N03GNJ datasheet (Ver-1.2) ──
        "rds_on":       2.9e-3,     # Ω typ @ Vgs=10V, ID=20A, 25°C
        "rds_on_max":   3.7e-3,     # Ω max
        "rds_tempco":   1.45,       # normalized @ 100°C (p3 curve)
        "rds_tempco_150": 1.70,     # normalized @ 150°C
        "qg_at_10v":    15e-9,      # C  (from gate charge curve p3 @ Vgs=10V)
        "qgd":          5.5e-9,     # C  gate-drain (Miller) charge
        "vgs":          10.0,       # V
        "rg":           15.0,       # Ω  external gate resistor
        "v_plateau":    3.0,        # V  Miller plateau (transfer curve p3)
        # Switching: Qgd / I_gate through Rg
        #   I_on  = (10-3)/15 = 0.47A → tr = 5.5nC/0.47A = 11.7ns
        #   I_off = 3/15      = 0.20A → tf = 5.5nC/0.20A = 27.5ns
        "tr":           11.7e-9,
        "tf":           27.5e-9,
        "vf_body_cold": 0.80,       # V  @ ~30A, 25°C (p4 curve extrapolated)
        "vf_body_hot":  0.65,       # V  @ ~30A, 100°C
        "trr":          14e-9,      # s  (p2)
        "qrr":          23e-9,      # C  (p2)
        "rth_jc":       2.27,       # °C/W (p2)
        "pd_max":       55.0,       # W
        "tj_max":       150.0,      # °C
        # Board
        "board_mm":     20,         # mm mounting pattern
        "board_area":   1030.0,     # mm² actual PCB (~31×33mm, from Edge.Cuts)
        "r_copper":     3.2e-3,     # Ω per phase trace
        "r_shunt":      0.2e-3,     # Ω
        "layers":       6,
        "oz_outer":     1,          # oz copper
        "oz_inner":     0.5,
    },
    "30x30": {
        "name":         "30×30  SP40N01GHNK (5×6mm)",
        # ── SP40N01GHNK datasheet (Ver-1.1) ──
        "rds_on":       1.2e-3,     # Ω typ @ Vgs=10V, ID=20A, 25°C
        "rds_on_max":   1.5e-3,     # Ω max
        "rds_tempco":   1.45,       # normalized @ 100°C (p3 curve)
        "rds_tempco_150": 1.70,     # normalized @ 150°C
        "qg_at_10v":    65e-9,      # C  (from gate charge curve p3 @ Vgs=10V)
        "qgd":          15.5e-9,    # C  gate-drain (Miller) charge
        "vgs":          10.0,       # V
        "rg":           8.0,        # Ω  external gate resistor
        "v_plateau":    3.5,        # V  Miller plateau (transfer curve p3, higher Vth)
        # Switching: Qgd / I_gate through Rg
        #   I_on  = (10-3.5)/8 = 0.81A → tr = 15.5nC/0.81A = 19.1ns
        #   I_off = 3.5/8      = 0.44A → tf = 15.5nC/0.44A = 35.2ns
        "tr":           19.1e-9,
        "tf":           35.2e-9,
        "vf_body_cold": 0.75,       # V  @ ~30A, 25°C (p3 source-drain diode curve)
        "vf_body_hot":  0.60,       # V  @ ~30A, 100°C
        "trr":          29e-9,      # s  (p2)
        "qrr":          113e-9,     # C  (p2) — much higher than SP40N03GNJ
        "rth_jc":       0.96,       # °C/W (p2) — better, larger package
        "pd_max":       130.0,      # W
        "tj_max":       150.0,      # °C
        # Board
        "board_mm":     30,         # mm mounting pattern
        "board_area":   1770.0,     # mm² actual PCB (~42×43mm, from Edge.Cuts)
        "r_copper":     2.0e-3,     # Ω per phase (wider traces, more area)
        "r_shunt":      0.2e-3,     # Ω
        "layers":       6,
        "oz_outer":     1,
        "oz_inner":     0.5,
    },
}

# ─── NSG2065Q gate driver (shared) ───
GATE_DRIVER = {
    "dead_time_typ":  200e-9,   # s  hardware dead time (100-300ns, p6)
    "dead_time_min":  100e-9,
    "dead_time_max":  300e-9,
    "io_source":      1.2,      # A
    "io_sink":        1.5,      # A
}

# ─── Thermal scenarios ───
# h = convective heat transfer coefficient (W/m²·K)
# θ_board = 1 / (h × A_both_sides)
THERMAL_SCENARIOS = {
    "still":        {"h": 15,   "label": "Still air (bench)"},
    "light_flow":   {"h": 50,   "label": "Light prop wash (~3m/s)"},
    "strong_flow":  {"h": 100,  "label": "Strong prop wash (~8m/s)"},
    "direct_blast": {"h": 150,  "label": "Direct motor blast (>10m/s)"},
}

# ─── PCB stackup options for thermal comparison ───
# Copper thickness: 1oz=35µm, 2oz=70µm, 0.5oz=17.5µm
# Thermal conductivity: Cu=385 W/(m·K), FR4=0.3 W/(m·K)
PCB_OPTIONS = {
    "jlcpcb_6L_1oz": {
        "label":    "JLCPCB 6L 1oz/0.5oz (current)",
        "oz_outer": 1.0, "oz_inner": 0.5, "layers": 6,
        "notes":    "Standard, free POFV via-in-pad",
    },
    "jlcpcb_6L_2oz": {
        "label":    "JLCPCB 6L 2oz/2oz (max multilayer)",
        "oz_outer": 2.0, "oz_inner": 2.0, "layers": 6,
        "notes":    "Max Cu at JLCPCB for 6L, ~2x bare board cost",
    },
    "jlcpcb_4L_2oz": {
        "label":    "JLCPCB 4L 2oz/2oz",
        "oz_outer": 2.0, "oz_inner": 2.0, "layers": 4,
        "notes":    "Cheaper than 6L, no free POFV",
    },
    "jlcpcb_6L_3oz": {
        "label":    "JLCPCB 6L 3oz/1oz (industry std ESC)",
        "oz_outer": 3.0, "oz_inner": 1.0, "layers": 6,
        "notes":    "What commercial 35A ESCs use",
    },
    "pcbway_6L_4oz": {
        "label":    "PCBWay 6L 4oz/2oz (heavy Cu)",
        "oz_outer": 4.0, "oz_inner": 2.0, "layers": 6,
        "notes":    "PCBWay supports >2oz on multilayer, premium cost",
    },
}


def board_theta(area_mm2: float, h: float) -> float:
    """Board-to-ambient thermal resistance (°C/W), both sides convecting."""
    area_m2 = area_mm2 * 2.0 * 1e-6
    return 1.0 / (h * area_m2)


def board_thermal_mass(area_mm2: float, layers: int, oz_outer: float, oz_inner: float,
                       board_thickness_mm: float = 1.6) -> float:
    """Board thermal capacitance in J/K.

    Accounts for FR-4 substrate and copper layers.
    FR-4: ρ=1.85 g/cm³, cp=1.1 J/(g·K)
    Cu:   ρ=8.96 g/cm³, cp=0.385 J/(g·K)
    """
    area_cm2 = area_mm2 * 1e-2  # mm² → cm²

    # FR-4 volume (approximate: total thickness minus copper)
    cu_outer_mm = oz_outer * 0.035  # mm per oz
    cu_inner_mm = oz_inner * 0.035 if oz_inner else 0.0175
    n_inner = max(layers - 2, 0)
    total_cu_mm = 2 * cu_outer_mm + n_inner * cu_inner_mm
    fr4_mm = board_thickness_mm - total_cu_mm
    fr4_vol_cm3 = area_cm2 * fr4_mm * 0.1  # cm²×mm→cm³ needs ×0.1
    fr4_mass = fr4_vol_cm3 * 1.85
    fr4_cth = fr4_mass * 1.1

    # Copper volume
    cu_vol_cm3 = area_cm2 * total_cu_mm * 0.1
    cu_mass = cu_vol_cm3 * 8.96
    cu_cth = cu_mass * 0.385

    return fr4_cth + cu_cth


def copper_resistance_scaled(r_base: float, oz_base: float, oz_new: float) -> float:
    """Scale copper trace resistance for different copper weight.
    R ∝ 1/thickness, so doubling oz halves resistance.
    """
    return r_base * oz_base / oz_new


def calc_phase_losses(i: float, v_bus: float, duty: float, f_pwm: float,
                      comp_pwm: bool, dead_time: float, p: dict,
                      r_copper_override: float = None) -> dict:
    """Calculate losses for one active phase pair."""
    rds = p["rds_on"] * p["rds_tempco"]  # hot Rds(on)
    vf = p["vf_body_hot"]
    r_cu = r_copper_override if r_copper_override else p["r_copper"]

    # Conduction
    p_cond_hs = i**2 * rds * duty
    if comp_pwm:
        p_cond_ls = i**2 * rds * (1.0 - duty)
        p_body = 0.0
    else:
        p_cond_ls = 0.0
        p_body = vf * i * (1.0 - duty)
    p_cond_low = i**2 * rds  # LOW-phase FET, 100% on

    # Switching (Miller plateau crossing)
    p_switch = 0.5 * v_bus * i * (p["tr"] + p["tf"]) * f_pwm

    # Dead time (both edges per PWM cycle)
    p_dead = vf * i * dead_time * 2.0 * f_pwm

    # Reverse recovery (Qrr-based model)
    p_rr = p["qrr"] * v_bus * f_pwm

    # Gate drive (HS at f_pwm, LS at commutation freq ~200Hz)
    p_gate = p["qg_at_10v"] * p["vgs"] * f_pwm + p["qg_at_10v"] * p["vgs"] * 200

    # Copper (both phase traces in the current path)
    p_copper = i**2 * r_cu * 2.0

    # Shunt
    p_shunt = i**2 * p["r_shunt"]

    p_fet = p_cond_hs + p_cond_ls + p_body + p_cond_low + p_switch + p_dead + p_rr + p_gate
    p_passive = p_copper + p_shunt
    p_total = p_fet + p_passive

    return {
        "p_cond_hs": p_cond_hs, "p_cond_ls": p_cond_ls, "p_body": p_body,
        "p_cond_low": p_cond_low, "p_switch": p_switch, "p_dead": p_dead,
        "p_rr": p_rr, "p_gate": p_gate, "p_copper": p_copper, "p_shunt": p_shunt,
        "p_fet": p_fet, "p_passive": p_passive, "p_total": p_total,
    }


def transient_time_to_tj(p_board: float, theta_ba: float, c_th: float,
                         tj_max: float, t_ambient: float) -> float:
    """Time (seconds) from ambient to Tj_max under constant power.

    Simple first-order RC model: ΔT(t) = ΔT_ss × (1 - e^(-t/τ))
    τ = C_th × θ_ba
    Returns float('inf') if steady-state ΔT < (Tj_max - T_ambient).
    """
    dt_max = tj_max - t_ambient
    dt_ss = p_board * theta_ba
    if dt_ss <= dt_max:
        return float('inf')  # never reaches Tj_max
    tau = c_th * theta_ba
    return -tau * math.log(1.0 - dt_max / dt_ss)


def print_full_report(profile_key: str, i: float, v_bus: float, duty: float,
                      f_pwm: float, comp_pwm: bool, dead_time: float, n_active: int):
    p = PROFILES[profile_key]
    rds_hot = p["rds_on"] * p["rds_tempco"]
    losses = calc_phase_losses(i, v_bus, duty, f_pwm, comp_pwm, dead_time, p)

    p_board = losses["p_total"] * n_active
    p_motor = v_bus * i * duty * n_active
    eff = p_motor / (p_motor + p_board) * 100 if p_motor > 0 else 0

    print("=" * 70)
    print(f"  4in1 ESC Power Loss Report  —  {p['name']}")
    print(f"  AM32 6-Step Trapezoidal  |  NSG2065Q gate driver")
    print("=" * 70)
    print(f"  Battery voltage:      {v_bus:.1f} V")
    print(f"  Phase current:        {i:.1f} A")
    print(f"  Duty cycle:           {duty*100:.1f}%")
    print(f"  PWM frequency:        {f_pwm/1e3:.0f} kHz")
    print(f"  Dead time:            {dead_time*1e9:.0f} ns  (NSG2065Q HW)")
    print(f"  Comp PWM:             {'ON' if comp_pwm else 'OFF'}")
    print(f"  Gate resistor:        {p['rg']:.0f}Ω  →  tr={p['tr']*1e9:.1f}ns  tf={p['tf']*1e9:.1f}ns")
    print(f"  Rds(on):              {p['rds_on']*1e3:.1f}mΩ cold → {rds_hot*1e3:.1f}mΩ hot (×{p['rds_tempco']})")
    print(f"  Active phases:        {n_active}")
    print("-" * 70)

    print(f"\n  Per phase pair (HS + LS MOSFET + copper):")
    print(f"    HS conduction:     {losses['p_cond_hs']:7.3f} W  (I²×Rds×D)")
    if comp_pwm:
        print(f"    LS sync rect:      {losses['p_cond_ls']:7.3f} W  (I²×Rds×(1-D))")
    else:
        print(f"    Body diode:        {losses['p_body']:7.3f} W  (Vf×I×(1-D))")
    print(f"    LOW-phase FET:     {losses['p_cond_low']:7.3f} W  (I²×Rds, 100%)")
    print(f"    Switching:         {losses['p_switch']:7.3f} W")
    print(f"    Dead time:         {losses['p_dead']:7.3f} W")
    print(f"    Reverse recovery:  {losses['p_rr']:7.3f} W  (Qrr={p['qrr']*1e9:.0f}nC)")
    print(f"    Gate drive:        {losses['p_gate']:7.3f} W")
    print(f"    ────────────────────────────────────────")
    print(f"    FET subtotal:      {losses['p_fet']:7.3f} W")
    print(f"    Copper (×2):       {losses['p_copper']:7.3f} W  ({p['r_copper']*1e3:.1f}mΩ/phase)")
    print(f"    Shunt:             {losses['p_shunt']:7.3f} W")
    print(f"    ────────────────────────────────────────")
    print(f"    Phase total:       {losses['p_total']:7.3f} W")

    print(f"\n  Board totals ({n_active} phases):")
    print(f"    Heat dissipation:  {p_board:7.2f} W")
    print(f"    Motor output:      {p_motor:7.1f} W")
    print(f"    Efficiency:        {eff:7.1f}%")

    # ─── Steady-state thermal ───
    area = p["board_area"]
    c_th = board_thermal_mass(area, p["layers"], p["oz_outer"], p["oz_inner"])

    print(f"\n  Steady-state thermal ({area:.0f}mm² board, {p['layers']}L "
          f"{p['oz_outer']:.0f}oz/{p['oz_inner']}oz):")
    print(f"  {'Scenario':<28s} {'θ':>6s}  {'ΔT':>6s}  {'Tj@25°C':>7s}  {'Tj@40°C':>7s}")
    print(f"  {'-'*62}")

    for key, sc in THERMAL_SCENARIOS.items():
        theta = board_theta(area, sc["h"])
        dt = p_board * theta
        tj25 = 25 + dt
        tj40 = 40 + dt
        w = " !! EXCEED" if tj25 > 150 else " ! HOT" if tj25 > 125 else ""
        print(f"  {sc['label']:<28s} {theta:5.1f}°/W  +{dt:4.0f}°C  {tj25:6.0f}°C  {tj40:6.0f}°C{w}")

    # ─── Transient thermal ───
    print(f"\n  Transient thermal (time to Tj=150°C from 25°C ambient):")
    print(f"  Board thermal mass: {c_th:.2f} J/K")
    print(f"  {'Scenario':<28s} {'τ':>6s}  {'t to 150°C':>10s}")
    print(f"  {'-'*50}")

    for key, sc in THERMAL_SCENARIOS.items():
        theta = board_theta(area, sc["h"])
        tau = c_th * theta
        t_max = transient_time_to_tj(p_board, theta, c_th, 150, 25)
        if t_max == float('inf'):
            t_str = "never"
        elif t_max < 1:
            t_str = f"{t_max*1000:.0f} ms"
        else:
            t_str = f"{t_max:.1f} s"
        print(f"  {sc['label']:<28s} {tau:5.1f}s   {t_str:>10s}")

    # ─── MOSFET limits ───
    p_worst_fet = max(
        losses["p_cond_hs"] + losses["p_switch"] + losses["p_dead"]/2 + losses["p_rr"],
        losses["p_cond_low"] + losses["p_body"] + losses["p_dead"]/2,
    )
    print(f"\n  MOSFET: RθJC={p['rth_jc']:.2f}°C/W  Pd_max={p['pd_max']:.0f}W  Tj_max={p['tj_max']:.0f}°C")
    print(f"  Worst single FET: {p_worst_fet:.2f}W → ΔTjc={p_worst_fet*p['rth_jc']:.1f}°C above pad")
    print("=" * 70)


def sweep(profile_key: str, currents: list, v_bus: float, duty: float,
          f_pwm: float, comp_pwm: bool, dead_time: float, n_active: int):
    p = PROFILES[profile_key]
    area = p["board_area"]
    c_th = board_thermal_mass(area, p["layers"], p["oz_outer"], p["oz_inner"])
    theta_fly = board_theta(area, 100)  # strong prop wash

    print()
    print(f"  {p['name']}  @  {v_bus:.0f}V  {duty*100:.0f}%  {f_pwm/1e3:.0f}kHz  "
          f"comp_pwm={'ON' if comp_pwm else 'OFF'}")
    print(f"  Board: {area:.0f}mm²  θ_propwash={theta_fly:.1f}°/W  C_th={c_th:.2f}J/K")
    print(f"  {'I':>6s}  {'Phase':>7s}  {'Board':>7s}  {'Eff':>5s}  "
          f"{'Tj_fly':>6s}  {'t→150°C':>8s}  {'Rating':>12s}")
    print(f"  {'-'*66}")

    for current in currents:
        losses = calc_phase_losses(current, v_bus, duty, f_pwm, comp_pwm, dead_time, p)
        p_board = losses["p_total"] * n_active
        p_motor = v_bus * current * duty * n_active
        eff = p_motor / (p_motor + p_board) * 100 if p_motor > 0 else 0
        tj_fly = 25 + p_board * theta_fly
        t_max = transient_time_to_tj(p_board, theta_fly, c_th, 150, 25)

        if t_max == float('inf'):
            t_str = "∞"
            if tj_fly < 100:
                rating = "continuous"
            elif tj_fly < 125:
                rating = "continuous*"
            else:
                rating = "marginal"
        elif t_max > 10:
            t_str = f"{t_max:.0f}s"
            rating = "burst OK"
        elif t_max > 3:
            t_str = f"{t_max:.1f}s"
            rating = "burst limit"
        else:
            t_str = f"{t_max:.1f}s"
            rating = "DANGER"

        print(f"  {current:5.0f}A  {losses['p_total']:6.2f}W  {p_board:6.1f}W  "
              f"{eff:4.1f}%  {tj_fly:5.0f}°C  {t_str:>8s}  {rating:>12s}")

    print()
    print("  continuous  = Tj < 100°C steady-state in prop wash")
    print("  continuous* = Tj 100-125°C (hot but survivable)")
    print("  marginal    = Tj 125-150°C (near limit)")
    print("  burst OK    = >10s to Tj_max (typical punch-out)")
    print("  burst limit = 3-10s to Tj_max")
    print()


def compare_boards(v_bus: float, duty: float, f_pwm: float, comp_pwm: bool,
                   dead_time: float, n_active: int):
    """Side-by-side comparison of both ESC variants."""
    currents = [5, 10, 15, 20, 25, 30, 35, 40, 50]

    print()
    print("=" * 78)
    print("  BOARD COMPARISON  —  20×20 vs 30×30")
    print(f"  {v_bus:.0f}V  {duty*100:.0f}% duty  {f_pwm/1e3:.0f}kHz  "
          f"comp_pwm={'ON' if comp_pwm else 'OFF'}  {n_active} phases")
    print("=" * 78)

    for key in ["20x20", "30x30"]:
        p = PROFILES[key]
        area = p["board_area"]
        c_th = board_thermal_mass(area, p["layers"], p["oz_outer"], p["oz_inner"])
        theta_fly = board_theta(area, 100)
        rds_hot = p["rds_on"] * p["rds_tempco"]

        print(f"\n  {p['name']}")
        print(f"  Rds(on)={rds_hot*1e3:.1f}mΩ hot  Rg={p['rg']:.0f}Ω  "
              f"Qrr={p['qrr']*1e9:.0f}nC  RθJC={p['rth_jc']:.2f}°/W")
        print(f"  θ_fly={theta_fly:.1f}°/W  C_th={c_th:.2f}J/K  "
              f"R_cu={p['r_copper']*1e3:.1f}mΩ/phase")
        print(f"  {'I':>6s}  {'Board W':>7s}  {'Eff':>5s}  "
              f"{'Tj_fly':>6s}  {'t→150°C':>8s}")
        print(f"  {'-'*44}")

        for current in currents:
            losses = calc_phase_losses(current, v_bus, duty, f_pwm, comp_pwm, dead_time, p)
            p_board = losses["p_total"] * n_active
            p_motor = v_bus * current * duty * n_active
            eff = p_motor / (p_motor + p_board) * 100 if p_motor > 0 else 0
            tj_fly = 25 + p_board * theta_fly
            t_max = transient_time_to_tj(p_board, theta_fly, c_th, 150, 25)
            t_str = "∞" if t_max == float('inf') else f"{t_max:.1f}s" if t_max < 60 else f"{t_max/60:.0f}m"
            warn = " !!" if tj_fly > 150 else " !" if tj_fly > 125 else ""
            print(f"  {current:5.0f}A  {p_board:6.1f}W  {eff:4.1f}%  "
                  f"{tj_fly:5.0f}°C  {t_str:>8s}{warn}")

    print()


def compare_pcb_options(profile_key: str, i: float, v_bus: float, duty: float,
                        f_pwm: float, comp_pwm: bool, dead_time: float, n_active: int):
    """Show impact of different PCB stackups on thermal performance."""
    p = PROFILES[profile_key]

    print()
    print(f"  PCB stackup comparison for {p['name']} @ {i:.0f}A {v_bus:.0f}V {duty*100:.0f}%")
    print("=" * 78)
    print(f"  {'Option':<38s} {'R_cu':>5s} {'Board W':>7s} {'Tj_fly':>6s} "
          f"{'t→150':>6s} {'Notes'}")
    print(f"  {'-'*76}")

    for opt_key, opt in PCB_OPTIONS.items():
        r_cu = copper_resistance_scaled(p["r_copper"], p["oz_outer"], opt["oz_outer"])
        losses = calc_phase_losses(i, v_bus, duty, f_pwm, comp_pwm, dead_time, p,
                                   r_copper_override=r_cu)
        p_board = losses["p_total"] * n_active
        area = p["board_area"]
        c_th = board_thermal_mass(area, opt["layers"], opt["oz_outer"], opt["oz_inner"])
        theta_fly = board_theta(area, 100)
        tj = 25 + p_board * theta_fly
        t_max = transient_time_to_tj(p_board, theta_fly, c_th, 150, 25)
        t_str = "∞" if t_max == float('inf') else f"{t_max:.1f}s"

        print(f"  {opt['label']:<38s} {r_cu*1e3:4.1f}  {p_board:6.1f}W  "
              f"{tj:5.0f}°C  {t_str:>5s}  {opt['notes']}")

    print()


def main():
    parser = argparse.ArgumentParser(
        description="4in1 ESC power loss calculator (AM32 6-step trapezoidal)",
        formatter_class=argparse.RawDescriptionHelpFormatter,
        epilog="""\
examples:
  %(prog)s -p 20x20 -i 30 -v 16.8 -d 80
  %(prog)s -p 30x30 -i 40 -v 25.2 -d 50 --comp-pwm
  %(prog)s -p 20x20 --sweep 5,10,15,20,25,30,35,40
  %(prog)s --compare -v 16.8 -d 80
  %(prog)s --pcb-options -p 30x30 -i 30 -v 16.8 -d 80
""")
    parser.add_argument("-p", "--profile", choices=["20x20", "30x30"], default="20x20",
                        help="ESC variant (default: 20x20)")
    parser.add_argument("-i", "--current", type=float, default=30.0)
    parser.add_argument("-v", "--voltage", type=float, default=16.8)
    parser.add_argument("-d", "--duty", type=float, default=80.0)
    parser.add_argument("-f", "--pwm-freq", type=float, default=24000)
    parser.add_argument("--dead-time", type=float, default=200e-9)
    parser.add_argument("--comp-pwm", action="store_true")
    parser.add_argument("-n", "--num-active", type=int, default=4)
    parser.add_argument("--sweep", type=str, default=None)
    parser.add_argument("--compare", action="store_true",
                        help="compare 20x20 vs 30x30 side by side")
    parser.add_argument("--pcb-options", action="store_true",
                        help="compare PCB stackup options")

    args = parser.parse_args()
    duty = args.duty / 100.0

    if args.compare:
        compare_boards(args.voltage, duty, args.pwm_freq, args.comp_pwm,
                       args.dead_time, args.num_active)
    elif args.pcb_options:
        compare_pcb_options(args.profile, args.current, args.voltage, duty,
                            args.pwm_freq, args.comp_pwm, args.dead_time, args.num_active)
    elif args.sweep:
        currents = [float(x) for x in args.sweep.split(",")]
        sweep(args.profile, currents, args.voltage, duty, args.pwm_freq,
              args.comp_pwm, args.dead_time, args.num_active)
    else:
        print_full_report(args.profile, args.current, args.voltage, duty,
                          args.pwm_freq, args.comp_pwm, args.dead_time, args.num_active)


if __name__ == "__main__":
    main()

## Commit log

2026-04-06 Update README to remove ordering details
    Removed mention of ordering from JLCPCB in the description and simplified the PCB details.
2026-04-30 Add design docs and EU production research
    - DESIGN_NOTES.md: dead time, Vds margin, bulk cap / hot-plug ring-up,
    commutation loop, switching frequency, BEC stage rationale, bring-up
    checklist
    - SOURCE-DOWN-OVERVIEW.md: source-down MOSFET landscape (Infineon
    OptiMOS, onsemi T10, Vishay Source Flip) for EU/V2 builds
    - EU_SOURCING.md, EU_PIPELINE.md, EU_PCB_FAB_QUOTES.md: EU production
    pipeline research (Belgium-based assembler + HDI fab quotes)
    - flash_openesc20.sh: ST-LINK V2 pogo-pin production flash script
    (bootloader + AM32)
    - README: link to DESIGN_NOTES.md from alternatives section
2026-04-30 DRC: tighten constraints for 2oz outer copper (V-beta stackup)
    Targets 6L / 2oz outers / 1oz inners / 1.6 mm / NP-155F per JLCPCB
    2oz design rules.
    Constraints:
    - min_clearance 0.0 -> 0.20 mm (JLC 2oz floor 0.16, +0.04 margin)
    - min_hole_to_hole 0.25 -> 0.50 mm
    - min_via_annular_width 0.10 -> 0.13 mm
    - min_silk_clearance 0.0 -> 0.15 mm
    - min_text_height 0.8 -> 1.0 mm
    - min_text_thickness 0.08 -> 0.15 mm
    - solder_mask_to_copper_clearance 0.0 -> 0.05 mm
    Net classes:
    - Power (+BATT, GND): 5.0 mm tracks, 1.2/0.6 vias
    - Phase (/ESC*/Motor*): 3.5 mm tracks, 0.8/0.4 vias
    - Gate (/ESC*/GH*, GL*): 0.5 mm tracks
    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
2026-04-30 V-beta schematic in progress: buck/inductor/TVS/MOSFET swaps
    Stan's V-beta edits via KiCad GUI:
    - U13 LMR54406DBVR placed (replacing LMR51420)
    - R119 = 115k for 10V output (Vfb=0.8V)
    - U5 inductor value updated to FTC160808S4R7MBCA (4.7uH)
    - D1 SMF24A-T13 TVS placed across +BATT/GND
    - 24x SP40N03GNJ -> DOY180N03T (TDFN3333-8PL)
    - 14x bulk caps in 1206 (replacing the 0805 swarm)
    - R74 = 10R 0201 added between VDD and VDDA (no ferrite)
    - Ferrites FB1-4 removed
    - LMR54406 footprint and 3D imported via easyeda2kicad
    - SMF24A-T13 footprint and 3D imported via easyeda2kicad
    Schematic still has hygiene issues (footprint namespace prefixes,
    cap/resistor R/C footprint swaps) to fix in a follow-up.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
    [4in1ESC.kicad_pcb, 4in1ESC.kicad_sch, ESC.kicad_sch]
2026-04-30 V-beta hygiene: footprint namespace cleanup, R/C footprint swaps
    Surgical line-by-line property-value substitutions (no structural
    changes; paren balance and newline count preserved as sanity checks).
    Changes (22 total):
    - Inductor U5 footprint: components: -> 4in1ESC: (top sheet, 2 occurrences:
    lib_symbols cache + instance)
    - NSG2065Q footprint: components: -> 4in1ESC:
    - AT32F421 footprint: ESCLibrary: -> 4in1ESC:
    - 17x resistor instances using Capacitor_SMD:C_0201_0603Metric
    swapped to Resistor_SMD:R_0201_0603Metric (ESC subsheet)
    scripts/v_beta_hygiene_fix.py: dry-run / --apply mode, byte-level
    operation in binary mode to avoid encoding mangles, paren-balance
    and newline-count sanit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
    [4in1ESC.kicad_sch, ESC.kicad_sch]
2026-04-30 Repo cleanup: archive stale docs and unused NextPCB scripts
    Move out of project root, into docs/archive/ (gitignored):
    - ALTERNATIVES.md, COST_ANALYSIS.md, DESIGN_NOTES.md (older reference)
    - EU_PCB_FAB_QUOTES.md, EU_PIPELINE.md, EU_SOURCING.md (V2/EU SKU planning)
    - SOURCE-DOWN-OVERVIEW.md (V2 MOSFET research)
    - scripts/generate_nextpcb_bom.py, generate_nextpcb_cpl.py (project
    uses JLCPCB/Fabrication Toolkit, not NextPCB)
    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
2026-05-07 alpha routing
    [4in1ESC.kicad_pcb, 4in1ESC.kicad_sch, ESC.kicad_sch]
2026-05-29 Migrate off iCloud and rename project to 4in1-mini
    Moved repo from iCloud Drive to ~/OpenDrone/4in1-mini. Renamed core
    KiCad project files 4in1ESC -> 4in1-mini; updated .kicad_pro/.kicad_prl
    filenames, root sheet name, 42 PCB sheetfile hints, and subsheet
    project instance refs (updated by KiCad). Library dirs kept as-is.
    Updated README.
    [4in1-mini.kicad_pcb, 4in1-mini.kicad_sch, 4in1ESC.kicad_pcb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]
2026-06-06 Routing update
    [4in1-mini.kicad_pcb]
2026-06-06 docs: reconcile README, add DESIGN_NOTES, publish it via gitignore
    Fix connector pin 4 (unconnected, was 'telemetry/signal'); add board
    outline (~31.3x33.1mm) and mounting. Add DESIGN_NOTES.md mirroring
    on-canvas KiCad comments and un-ignore it (README + DESIGN_NOTES are the
    public docs). Mirror the 30x30 sibling repo's structure.
2026-06-06 docs: extended-DShot telemetry note, add buck/TVS/decoupling notes from canvas
2026-06-06 meta: standardize symbol BOM/doc fields (20x20)
    Add MPN/Manufacturer/LCSC/Digi-Key/Mouser/Farnell/Cost to every sourced
    part. Source MPN + LCSC unit cost via keyless LCSC; Manufacturer set for
    known ICs (TI, ArteryTek, Littelfuse). Clear legacy LCSC_Part, strip CJK
    from Manufacturer. SMF24A-T13/DOY180N03T not in LCSC search -> MPN kept,
    Cost blank. Digi-Key/Mouser/Farnell left blank pending API creds.
    Properties-only -- no connectivity change. Also carries the finalized
    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
    [4in1-mini.kicad_sch, ESC.kicad_sch]
2026-06-06 docs: add standardized board renders + README refs
2026-06-06 docs: reference board renders in README
2026-06-06 restructure: move KiCad project into hardware/ (20x20)
    Mirror the OpenFC-Lite layout: move the KiCad project, project-local
    libraries, lib tables, production, datasheets, tools/scripts, design
    docs and exports under hardware/. Root keeps README, LICENSE, CLAUDE.md,
    images/, licensing/. All paths are ${KIPRJMOD}-relative so nothing
    breaks; verified netlist (167 comps) and DRC resolve from the new
    location. README/CLAUDE paths updated. (CLAUDE.md is git-ignored.)
    [4in1-mini.kicad_pcb, 4in1-mini.kicad_sch, ESC.kicad_sch]
2026-06-06 docs: show board renders side-by-side (OpenFC-Lite-Mini style)
2026-06-07 docs: via-free board renders
    Re-render top/bottom board images with vias removed for a cleaner look.
    KiCad cannot render tented vias, so vias were temporarily stripped via the
    pcbnew API for rendering only; source .kicad_pcb files are unchanged.
2026-06-07 docs: re-render boards without floor shadows
    Re-render top/bottom images at basic quality so the soldermask floor
    shadow halo is gone. Vias still stripped for the render only (via pcbnew),
    source .kicad_pcb files unchanged.
2026-06-07 docs: render boards without solder paste
    Strip the solder-paste layer (and vias) for the render only so SMD pads
    show as clean copper instead of gray paste deposits. Source .kicad_pcb
    files unchanged.
2026-06-07 docs: remove DESIGN_NOTES, trim README boilerplate
    - Delete DESIGN_NOTES.md (and its gitignore exception)
    - Drop the Manufacturing / production-export section
    - Remove the canonical-reference boilerplate blurb
    - ESC boards: AM32 bootloader ships pre-loaded, firmware flashed via am32.ca
